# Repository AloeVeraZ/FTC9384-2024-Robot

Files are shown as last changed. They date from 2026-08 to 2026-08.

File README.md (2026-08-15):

<div align="center">

# EggWUUUHH · FTC 9384 Competition Robot

### FTC Team 9384 Hydraulic Hydras · 2023–2024 CENTERSTAGE Season Robot CAD







<picture>
  FTC Team 9384's 2023–2024 robot EggWUUUHH
</picture>

Open mechanical design solid models, competition photography, engineering documentation, and subsystem CAD for FTC Team 9384's CENTERSTAGE robot.

<strong>Quick navigation:</strong><br>
[Robot Overview](#about-the-robot) | [CAD Downloads](#cad-downloads) | [Design History](docs/DESIGN_HISTORY.md) | [Engineering Portfolio](#engineering-documentation) | [GrabCAD Model](https://grabcad.com/library/ftc-9384-2023-2024-robot-1)

</div>

---

## About the Robot

**EggWUUUHH** is the official competition machine built by FTC Team 9384 Hydraulic Hydras for the 2023–2024 **CENTERSTAGE** season. This repository preserves the complete master assembly alongside discrete subsystem models (custom plate chassis, 3-stage compliant intake, linear lift, scoring outtake, drone launcher, and winch climber).

The models were originally published on [GrabCAD by Angelo Demetroulakos](https://grabcad.com/library/ftc-9384-2023-2024-robot-1) and are mirrored locally in neutral STEP format for open accessibility without third-party account requirements.

| System Specification | Implementation Details |
| --- | --- |
| Drivetrain | 4-wheel independent Mecanum drive on custom 4-plate aluminum chassis |
| Intake mechanism | 3-stage active collection: compliant star wheels, counter-rollers, and flexible sweepers |
| Vertical lift | Multi-stage cascading linear drawer slides with 3D-printed continuous string rigging |
| Scoring outtake | Dual-pixel articulated box with mechanical retention pincher and backdrop landing skids |
| Aerial drone launcher | Spring-tensioned sled with dual servo release and angle elevation control |
| Rigging & climber | High-speed motorized winch pulling side-mounted pivoting stage truss hooks |

## Robot and Game

During CENTERSTAGE matches, robots collected hexagonal plastic pixels and placed them on an angled 60° backdrop to create continuous mosaic scoring patterns. Endgame opportunities rewarded suspending the entire robot chassis from the central stage truss and launching a paper drone into designated zones.

<div align="center">

| Master Robot Front 3/4 View | Rear Subsystem & Wiring View |
| :---: | :---: |
| FTC 9384 EggWUUUHH robot photograph | Rear view of the FTC 9384 EggWUUUHH robot |

</div>

<div align="center">

| Active 3-Stage Intake Iteration | Side-Mounted High-Speed Winch Climber |
| :---: | :---: |
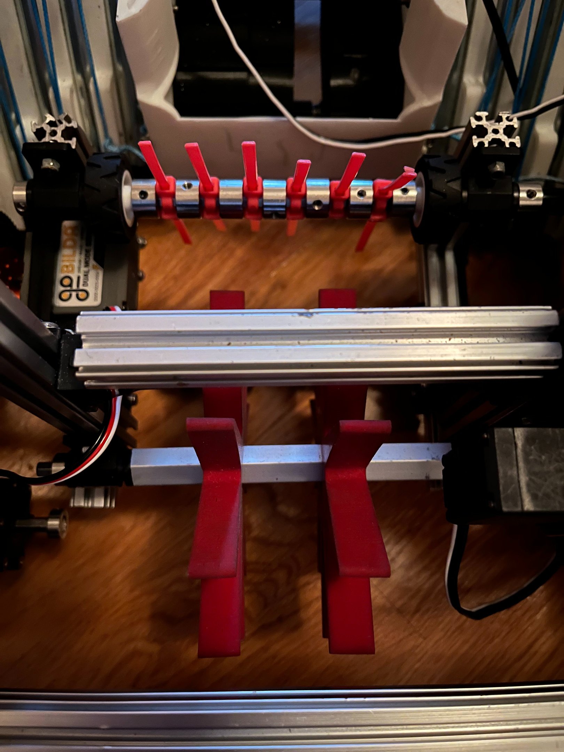
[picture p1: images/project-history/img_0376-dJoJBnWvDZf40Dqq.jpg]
Early active intake iteration
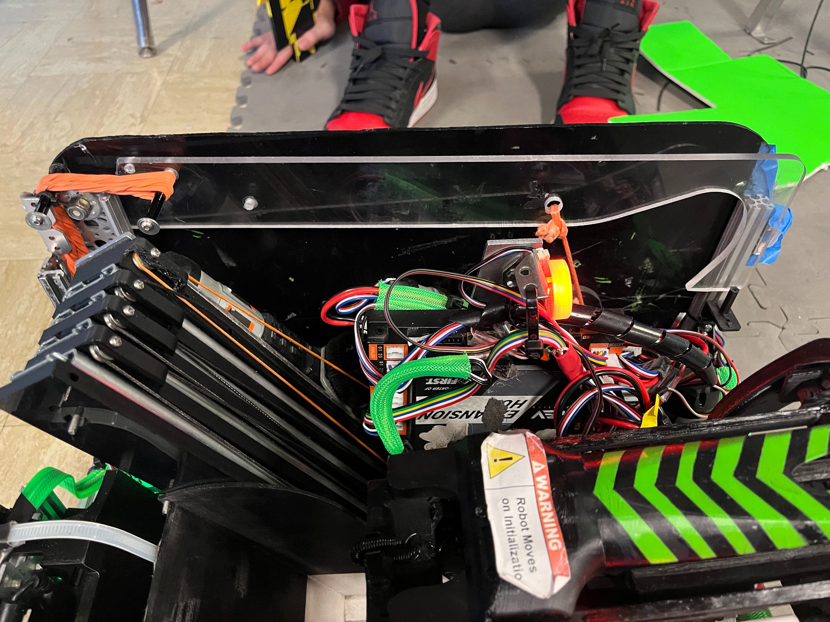
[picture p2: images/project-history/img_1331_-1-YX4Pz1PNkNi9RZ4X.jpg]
Final side-mounted climbing mechanism
|  |  |

</div>

Read the full technical design evolution across all 4 competition iterations in [`docs/DESIGN_HISTORY.md`](docs/DESIGN_HISTORY.md).

## CAD Downloads

All solid models are exported in neutral ISO 10303 STEP format compatible with Fusion 360, Onshape, SolidWorks, Autodesk Inventor, and FreeCAD:

| Subsystem Model | Description & Hierarchy | Direct Download |
| --- | --- | :---: |
| `Main v18.step` | Complete master competition robot assembly | [Download STEP](CAD/Main%20v18.step?raw=1) |
| `Final Chassis V130.step` | Four-plate aluminum chassis frame and drivetrain | [Download STEP](CAD/Final%20Chassis%20V130.step?raw=1) |
| `Chassis and Climber.step` | Integrated chassis with side-mounted winch hooks | [Download STEP](CAD/Chassis%20and%20Climber.step?raw=1) |
| `Intake.step` | 3-stage active compliant roller intake assembly | [Download STEP](CAD/Intake.step?raw=1) |
| `Lift and Outtake.step` | Cascading slide rigging and dual-pixel delivery box | [Download STEP](CAD/Lift%20and%20Outtake.step?raw=1) |
| `Logitech920Mount_v4.step` | Custom angled Logitech C920 USB camera bracket | [Download STEP](CAD/Logitech920Mount_v4.step?raw=1) |

## Engineering Documentation

The team's complete judged documentation submitted at the NYC Championship:

| Document | Technical Scope | Direct Link |
| --- | --- | :---: |
| **Engineering Portfolio** | 15-page concise executive judging document | [Open Portfolio PDF](Portfolio%26Notebook/9384%202024%20Portfolio%20FINAL.pdf) |
| **Engineering Notebook** | Comprehensive season-long day-by-day technical log | [Open Notebook PDF](Portfolio%26Notebook/9384%20Notebook%202024%20FINAL.pdf) |

## Integrity Verification

SHA-256 integrity checksums for all distributed STEP files, PDFs, and high-resolution media are maintained in [`CHECKSUMS.sha256`](CHECKSUMS.sha256).

## License & Attribution

Original models, renders, photography, and documentation are licensed under the **[Creative Commons Attribution 4.0 International License](LICENSE)**.

```text
Based on the FTC 9384 2023–2024 Robot by Angelo Demetroulakos and FTC Team 9384 Hydraulic Hydras,
licensed under CC BY 4.0. Source: https://github.com/AloeVeraZ/FTC9384-2024-Robot
```

---

<div align="center">

Built by **FTC Team 9384 · Hydraulic Hydras**

</div>

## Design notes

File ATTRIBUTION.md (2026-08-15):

# Attribution and reuse

The original robot design, CAD exports, images, and documentation in this repository are made available under the [Creative Commons Attribution 4.0 International License](LICENSE), except where a file or section is marked otherwise.

## Required credit

When you publicly share this material or something derived from it, provide credit in a manner reasonable for the medium. The attribution should identify the work and creators, link to the original repository where practical, link to CC BY 4.0, and state whether you made changes.

Suggested attribution:

> Based on the FTC 9384 2023–2024 Robot by Angelo Demetroulakos and FTC Team 9384 Hydraulic Hydras, licensed under CC BY 4.0. Source: https://github.com/AloeVeraZ/FTC9384-2024-Robot. Changes: [describe your changes, or write “none”].

For a physical robot, printed part, video, social-media post, publication, or competition portfolio, the credit may appear in a caption, description, credits section, accompanying documentation, or another reasonably visible location.

## Attribution details

- **Title:** FTC 9384 2023–2024 Robot “EggWUUUHH”
- **Creators:** Angelo Demetroulakos and FTC Team 9384 Hydraulic Hydras
- **Source:** https://github.com/AloeVeraZ/FTC9384-2024-Robot
- **Original GrabCAD publication:** https://grabcad.com/library/ftc-9384-2023-2024-robot-1
- **Repository:** https://github.com/AloeVeraZ/FTC9384-2024-Robot
- **License:** Creative Commons Attribution 4.0 International — https://creativecommons.org/licenses/by/4.0/

## Scope

CC BY 4.0 applies only to material that the repository contributors own or are authorized to license. It does not grant rights to third-party trademarks, team marks, product names, vendor components, or other independently owned material depicted or referenced in the files. Those items remain subject to their respective owners' terms.

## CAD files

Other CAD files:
CAD/Main v18.step
CAD/Chassis and Climber.step
CAD/Intake.step
CAD/Logitech920Mount_v4.step
CAD/Lift and Outtake.step
CAD/Final Chassis V130.step

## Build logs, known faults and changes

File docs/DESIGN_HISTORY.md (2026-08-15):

# EggWUUUHH design history

This document preserves and reorganizes the robot-specific engineering record from an earlier project write-up. It is an original summary rather than a copy of that write-up. The associated robot media was archived here on August 1, 2026.

## Challenge and design goals

FTC Team 9384 began work on September 9, 2023 for the CENTERSTAGE season. The game rewarded robots for collecting thin hexagonal pixels and placing them on an angled backdrop or in marked field zones. Endgame tasks added the option to hang from the stage truss and launch a paper airplane into an external scoring area.

These tasks drove several top level requirements:

- reach multiple backdrop heights without sacrificing a compact starting configuration;
- collect and retain up to two pixels quickly;
- place pixels against an angled scoring surface with predictable control;
- preserve mecanum mobility while packaging several mechanisms inside the chassis;
- launch the paper airplane repeatably; and
- add a fast, reliable suspension mechanism before the championship stage.

The robot passed through four major competition iterations.

## Iteration 1 — kickoff through Qualifier 2

### Linear slides

The backdrop's height and angle led the team to a vertically extending slide system. Standard drawer slides were stacked together with 3D printed parts serving as both spacers and pulley supports. A motor changed the direction of tension in the slide string to extend or retract the assembly.

### Chassis

The mecanum drive used a custom chassis built from four parallel aluminum plates. Plate profiles incorporated mounting holes and mechanism clearances, while aluminum extrusions tied the structure together.

### Intake

The first active intake used three stages so two pixels could move through the robot quickly. Star wheels initially gripped the game piece, counter rotating rollers pulled it farther inward, and flexible zip ties swept it into the outtake area.

### Outtake

The initial outtake held the pixels in a box and used 3D printed flexible belts to eject them. It was fast, but could not release a pixel at the angle needed to score reliably on the backdrop. That limitation drove the next redesign.

### Plane launcher

A spring provided the launch energy. One servo released the spring and another raised the launcher to its firing angle, separating the aiming and trigger functions.

## Iteration 2 — Qualifier 2 through Qualifier 4

The chassis, intake, slides, and plane launcher concepts were retained. Most development focused on the outtake.

The replacement outtake pivoted downward until it contacted the backdrop, allowing each pixel to slide into place rather than being thrown toward the angled surface. A pinching mechanism retained the first loaded pixel while a second pixel waited above it, making controlled two pixel cycles possible.

## Iteration 3 — Qualifier 4 through Super Qualifier

The team preserved the proven core mechanisms and added a small servo driven pincher to the intake. During autonomous operation, this arm could rotate downward and collect pre stacked pixels. The plane launcher's working mechanism stayed the same while its supporting frame was refined.

## Iteration 4 — Super Qualifier through State Championship

The mature chassis, slides, intake, outtake, and launcher remained in service. The major addition was the climber.

After testing multiple climbing concepts, the team selected a winch driven design for its speed, stiffness, and holding torque. Hooks on both sides of the robot pivoted toward the rear. String attached near each hook's center pulled the mechanism downward, while rubber bands provided passive assistance to raise its resting height. The winch then supported the robot from the truss.

## Mechanism takeaways

- Keeping successful subsystems unchanged between events reduced risk and concentrated effort on the mechanisms that limited scoring.
- The outtake redesign changed the interaction with the field: supporting the box against the backdrop was more repeatable than ejecting toward it.
- A small intake attachment added autonomous capability without replacing the established pixel path.
- The final climber combined active winch force with passive elastic assistance, reducing the number of powered operations required to deploy the hooks.

## Video reference

- [Official 2023–2024 FTC CENTERSTAGE game animation](https://www.youtube.com/watch?v=6e-5Uo1dRic&t=30s)

The video is linked rather than mirrored because it is third party material published by FIRST.

## Archived project media

The files below are local copies of the original project images. They are kept under their source filenames to preserve provenance.

<details>
<summary><strong>Open the complete 20 image development gallery</strong></summary>

<table>
  <tr>
    <td width="50%">Robot development image img 0376</td>
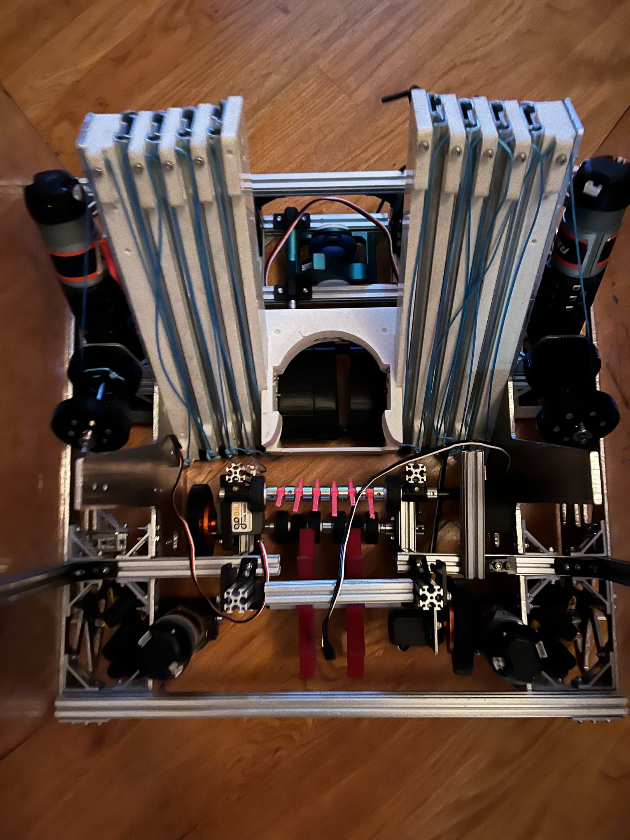
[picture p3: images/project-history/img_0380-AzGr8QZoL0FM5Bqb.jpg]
Robot development image img 0380
    <td width="50%"></td>
  </tr>
  <tr>
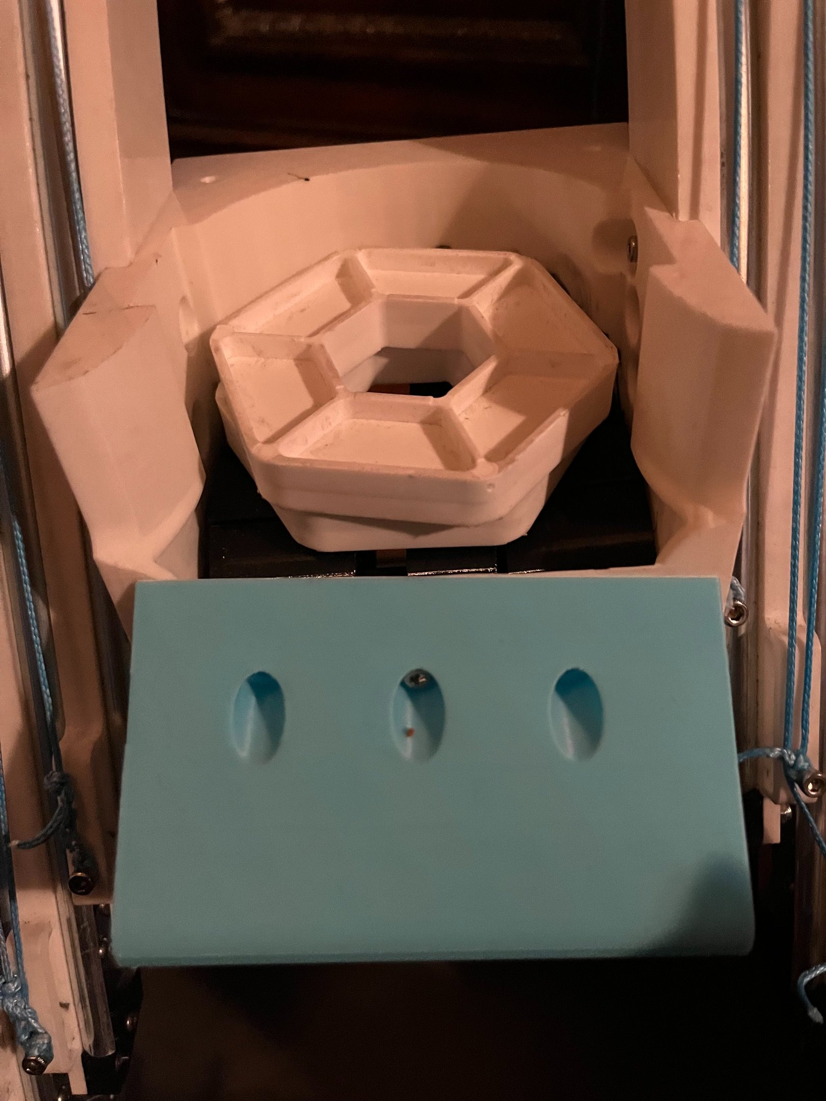
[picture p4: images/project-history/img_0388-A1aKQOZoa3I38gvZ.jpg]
Robot development image img 0388
    <td></td>
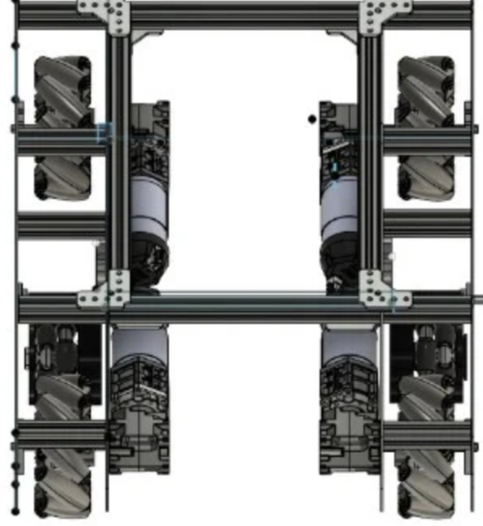
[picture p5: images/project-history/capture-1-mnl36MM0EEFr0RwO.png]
Robot CAD capture 1
    <td></td>
  </tr>
  <tr>
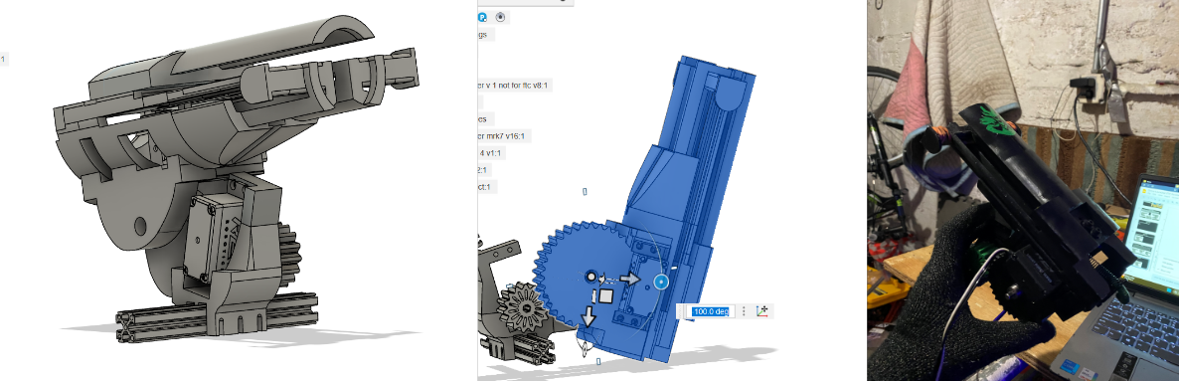
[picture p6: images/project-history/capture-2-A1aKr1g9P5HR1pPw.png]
Plane launcher design capture
    <td></td>
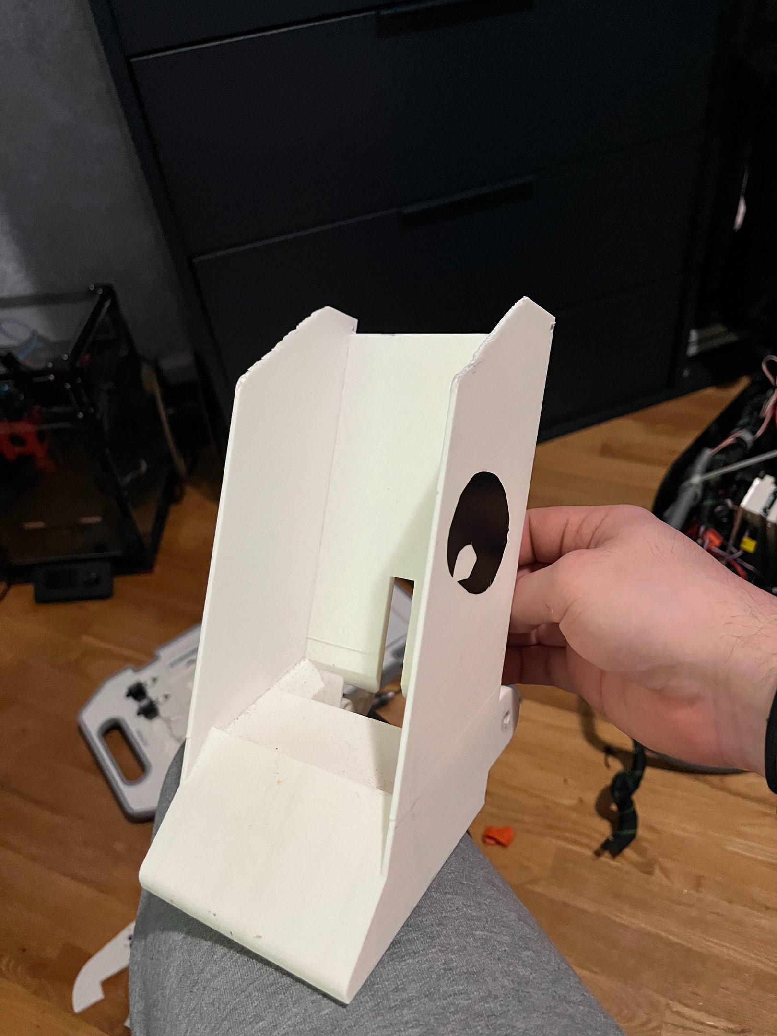
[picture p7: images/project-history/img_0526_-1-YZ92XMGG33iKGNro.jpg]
Robot development image img 0526
    <td></td>
  </tr>
  <tr>
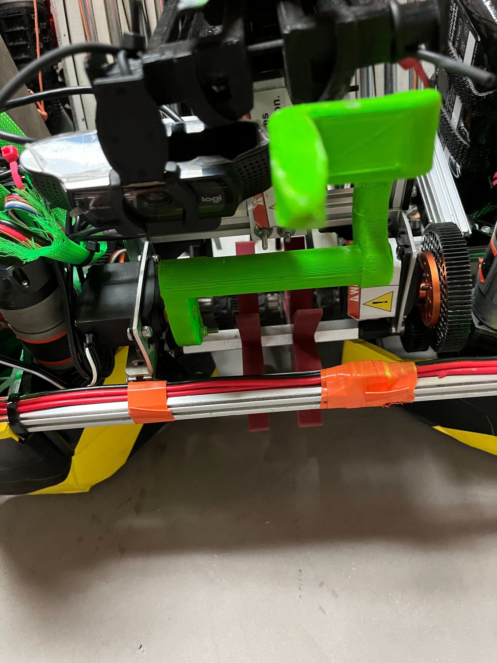
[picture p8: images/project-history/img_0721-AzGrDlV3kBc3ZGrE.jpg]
Robot development image img 0721
    <td></td>
    <td>Climber mechanism development image</td>
  </tr>
  <tr>
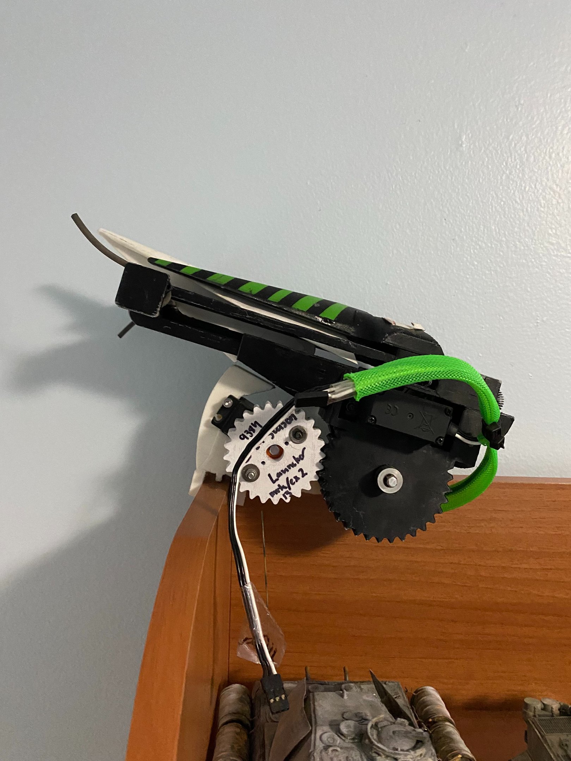
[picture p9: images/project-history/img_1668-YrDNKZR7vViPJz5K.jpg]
Robot development image img 1668
    <td></td>
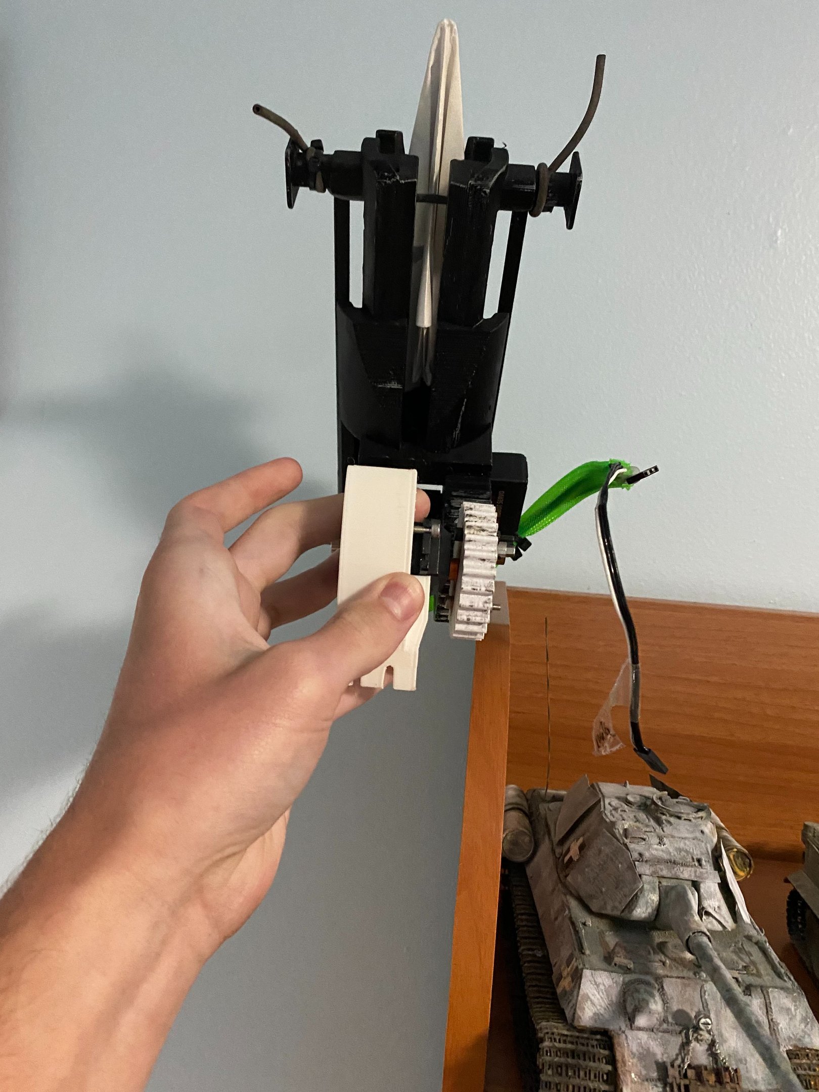
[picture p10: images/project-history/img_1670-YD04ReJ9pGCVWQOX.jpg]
Robot development image img 1670
    <td></td>
  </tr>
  <tr>
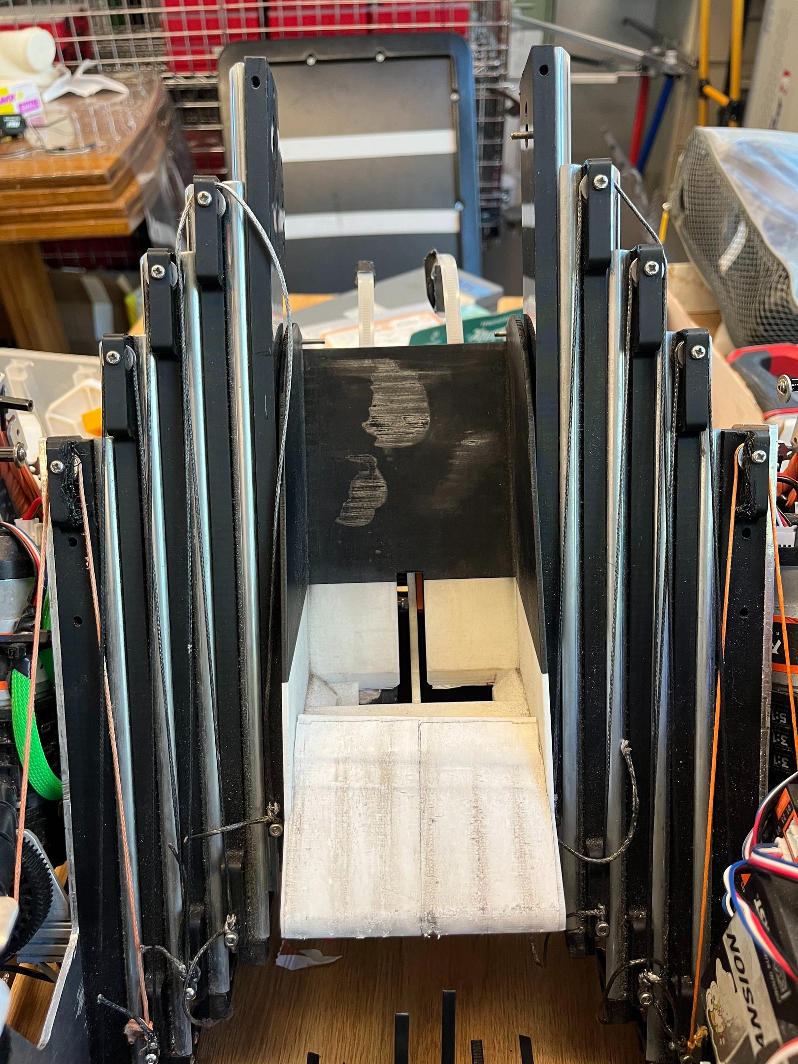
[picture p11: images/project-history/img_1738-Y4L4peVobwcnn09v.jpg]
Robot development image img 1738
    <td></td>
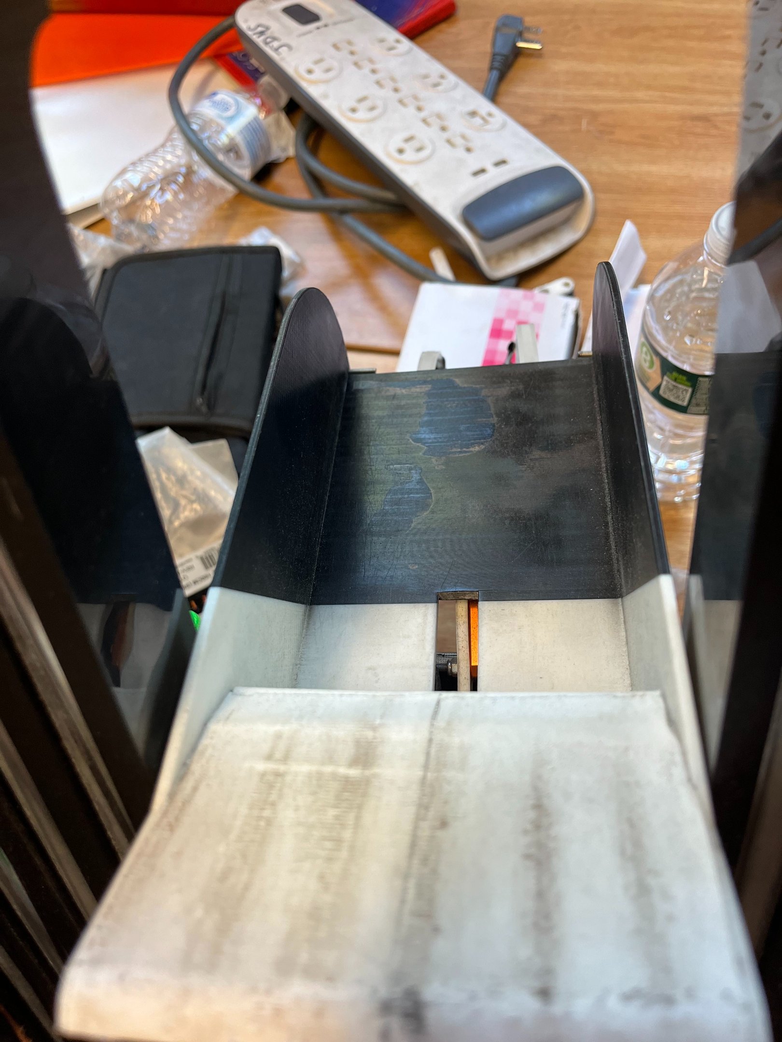
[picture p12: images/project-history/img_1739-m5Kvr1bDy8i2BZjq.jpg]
Robot development image img 1739
    <td></td>
  </tr>
  <tr>
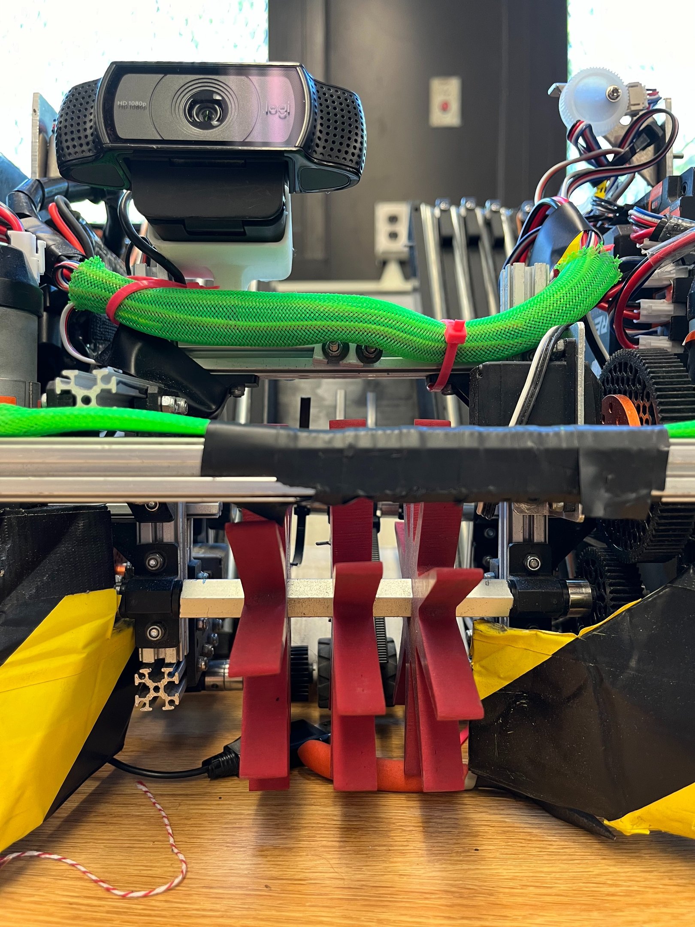
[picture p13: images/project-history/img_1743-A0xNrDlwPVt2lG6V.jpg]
Robot development image img 1743
    <td></td>
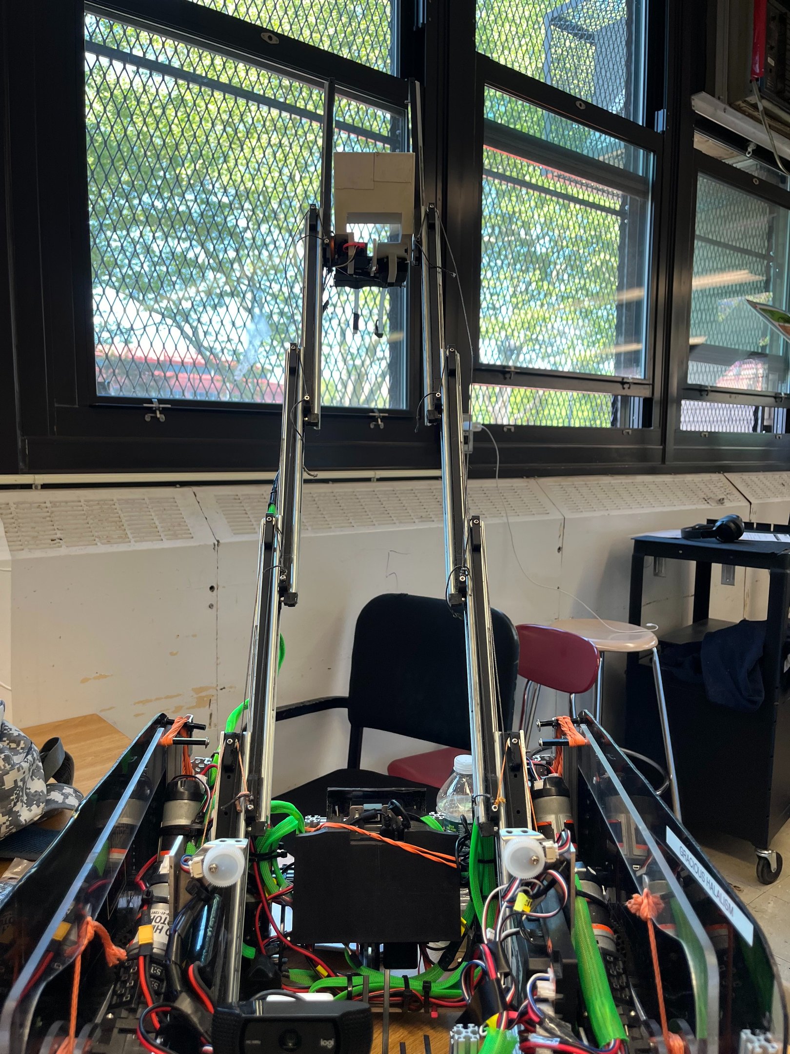
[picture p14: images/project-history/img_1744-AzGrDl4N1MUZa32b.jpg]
Robot development image img 1744
    <td></td>
  </tr>
  <tr>
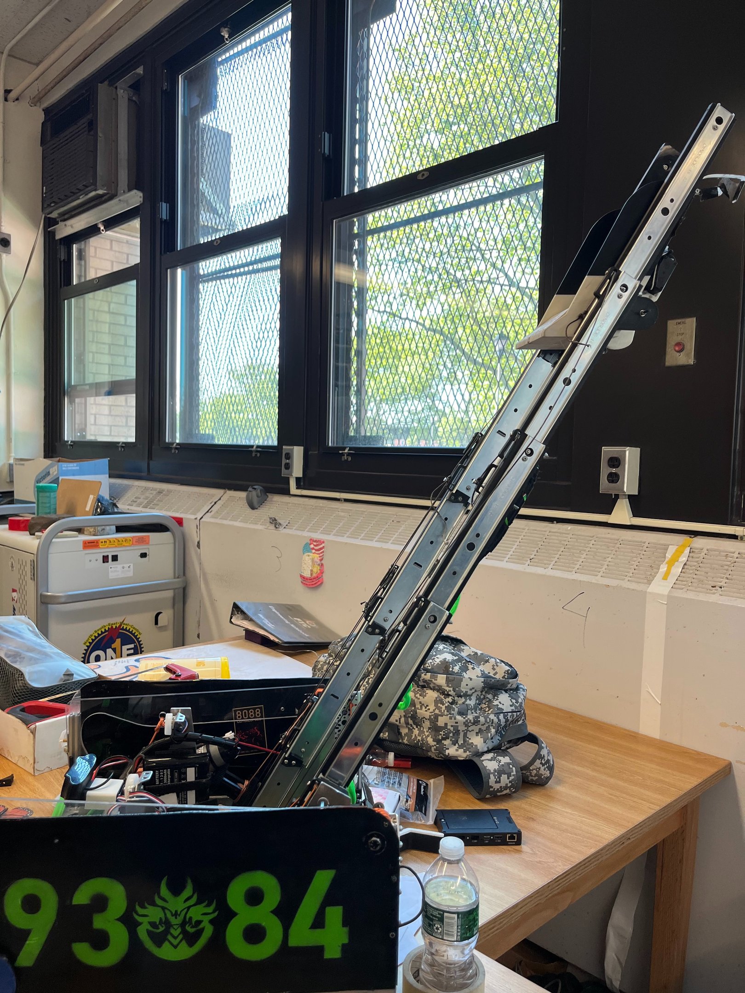
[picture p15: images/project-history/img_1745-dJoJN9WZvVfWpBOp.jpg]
Robot development image img 1745
    <td></td>
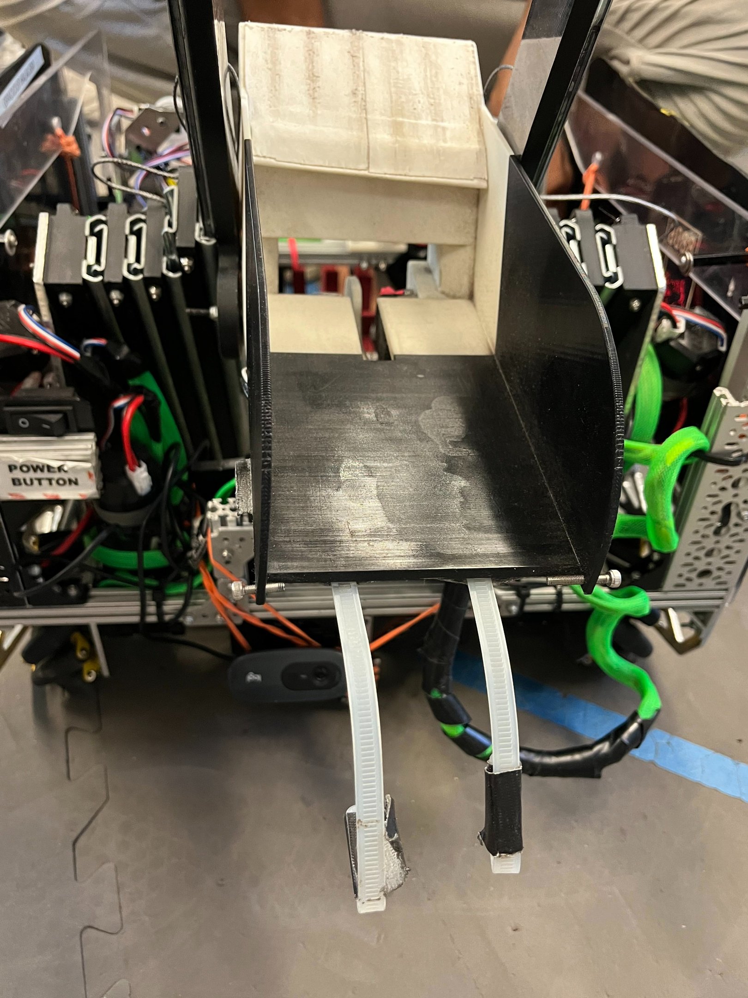
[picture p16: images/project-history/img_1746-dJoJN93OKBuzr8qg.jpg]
Robot development image img 1746
    <td></td>
  </tr>
  <tr>
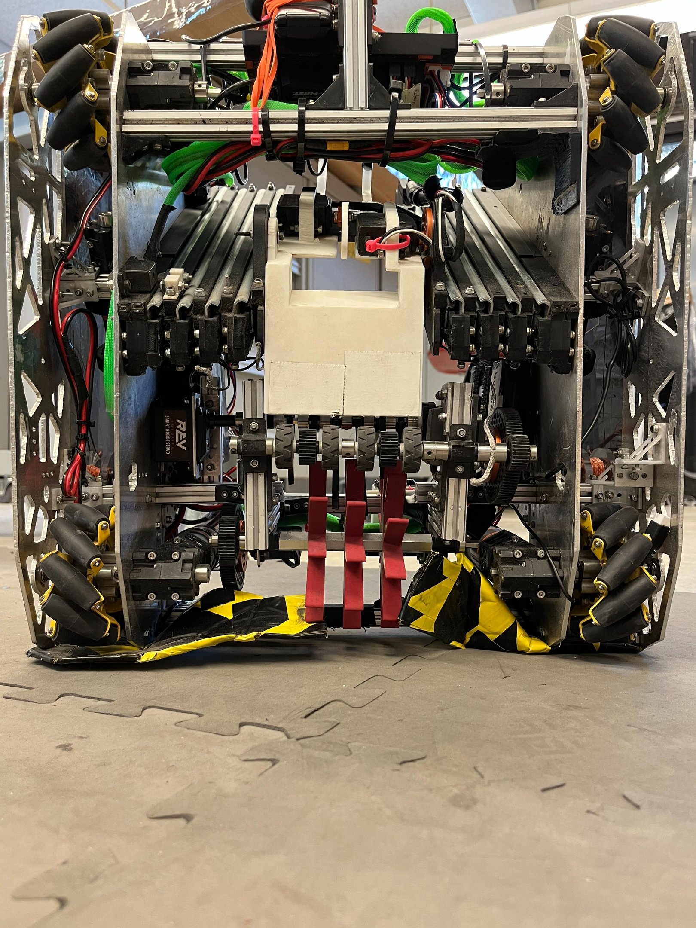
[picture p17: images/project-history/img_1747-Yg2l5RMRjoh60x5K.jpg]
Robot development image img 1747
    <td></td>
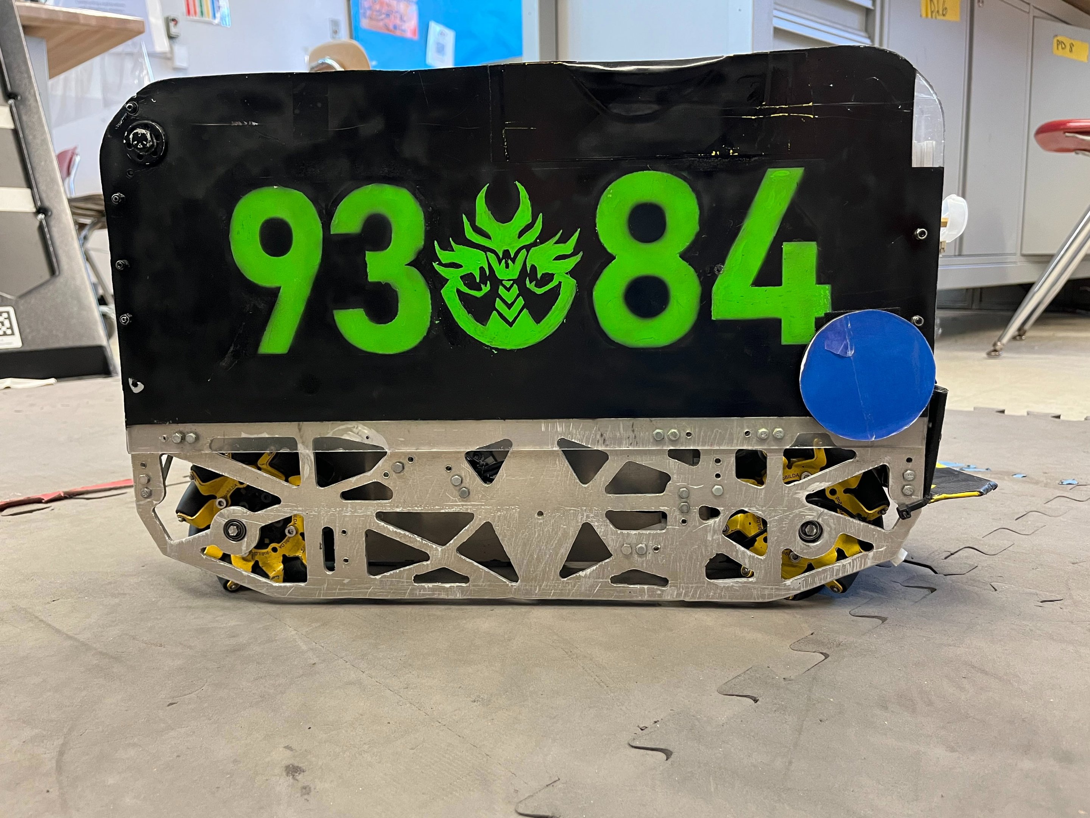
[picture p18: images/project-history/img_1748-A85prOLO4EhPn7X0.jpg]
Robot development image img 1748
    <td></td>
  </tr>
  <tr>
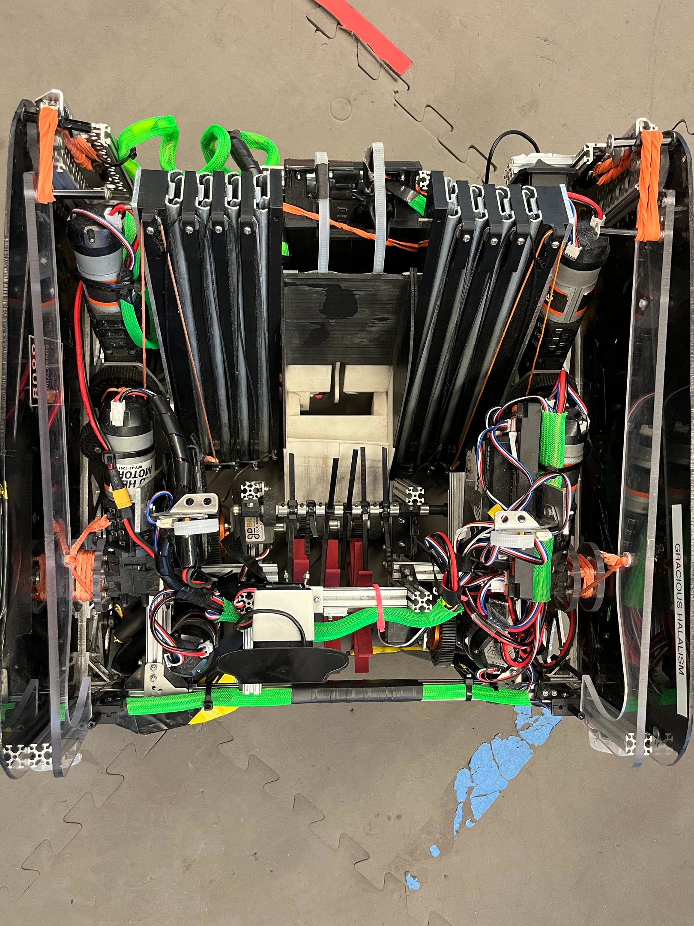
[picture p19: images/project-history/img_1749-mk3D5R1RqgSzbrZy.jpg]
Robot development image img 1749
    <td></td>
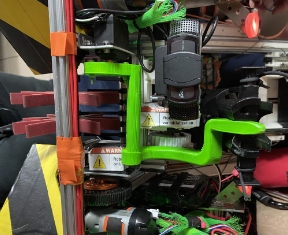
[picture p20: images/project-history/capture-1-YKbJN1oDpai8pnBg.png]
Robot CAD capture 2
    <td></td>
  </tr>
</table>

</details>

## Related resources

- [CAD downloads](../README.md#cad-downloads)
- [Engineering portfolio and notebook](../README.md#engineering-documentation)
- [Original GrabCAD publication](https://grabcad.com/library/ftc-9384-2023-2024-robot-1)

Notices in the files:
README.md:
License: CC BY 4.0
